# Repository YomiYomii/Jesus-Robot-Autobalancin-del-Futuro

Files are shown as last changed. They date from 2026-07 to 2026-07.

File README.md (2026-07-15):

# 🤖 Jesucristo, el Robot Auto-Balancín del Futuro
 
<p align="center">
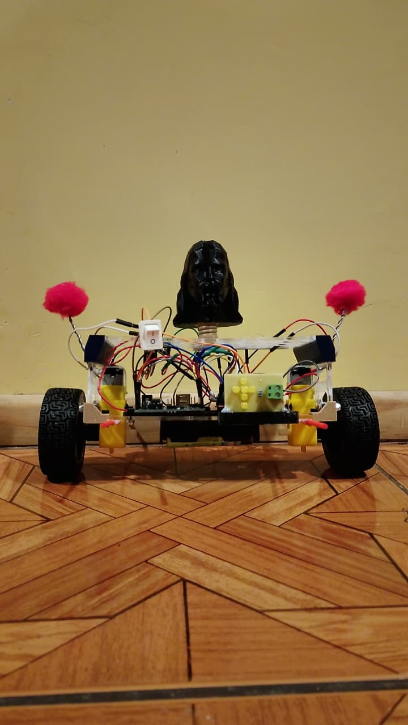
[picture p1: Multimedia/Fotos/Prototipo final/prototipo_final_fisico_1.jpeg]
  
</p>
<p align="center">
  <i>Robot auto-balancín de 2 ruedas con control PID, inspirado en "Jesucristo, el robot del futuro" de Zorman.</i>
</p>

<p align="center">
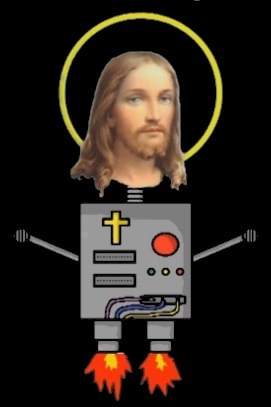
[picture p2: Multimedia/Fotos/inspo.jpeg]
Inspiración: Jesucristo, el robot del futuro
  <br>
  <i>Referencia de inspiración.</i>
</p>
 
- [Descripción](#-descripción)
- [Galería del proyecto](#-galería-del-proyecto)
- [Estructura del repositorio](#-estructura-del-repositorio)
- [Integrantes](#-integrantes)
- [Curso y agradecimientos](#-curso-y-agradecimientos)
- [Referencias](#-referencias)

## Descripción
 
Este proyecto consiste en el diseño, manufactura y programación de un **mini robot auto-balancín** de 2 ruedas, inspirado estéticamente en *Jesucristo, el robot del futuro*, personaje de la canción homónima de Zorman.
 
El robot utiliza un **sensor/giroscopio MPU6050** para medir su ángulo de inclinación y un **controlador PID** (implementado en Arduino IDE) para calcular la señal de corrección enviada a dos motores DC mediante un driver L298N, logrando mantener el equilibrio de forma autónoma.
 
El desarrollo pasó por múltiples iteraciones de diseño CAD y prototipado físico (impresión 3D FDM y corte láser en acrílico), hasta llegar a una versión final que integra mejoras estéticas (cruz de LEDs, brazos de alambre, cabeza) y estructurales (mejor manejo de cableado y sujeción de componentes).
 
Este repositorio reemplaza el informe final del proyecto, documentando de forma abierta y reproducible todo el proceso de diseño, fabricación, electrónica y control.

## Galería del proyecto

| Prototipo final | Diagrama de control | Constantes PID |
|:---:|:---:|:---:|
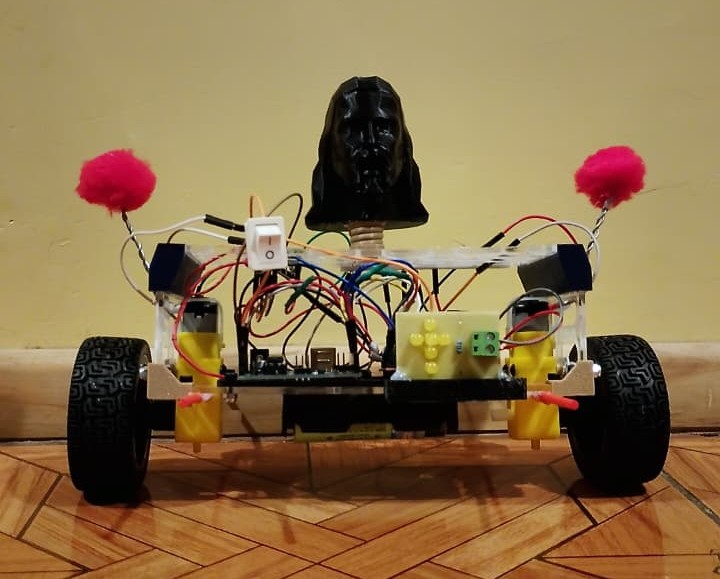
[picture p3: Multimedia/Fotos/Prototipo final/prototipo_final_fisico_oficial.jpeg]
Prototipo
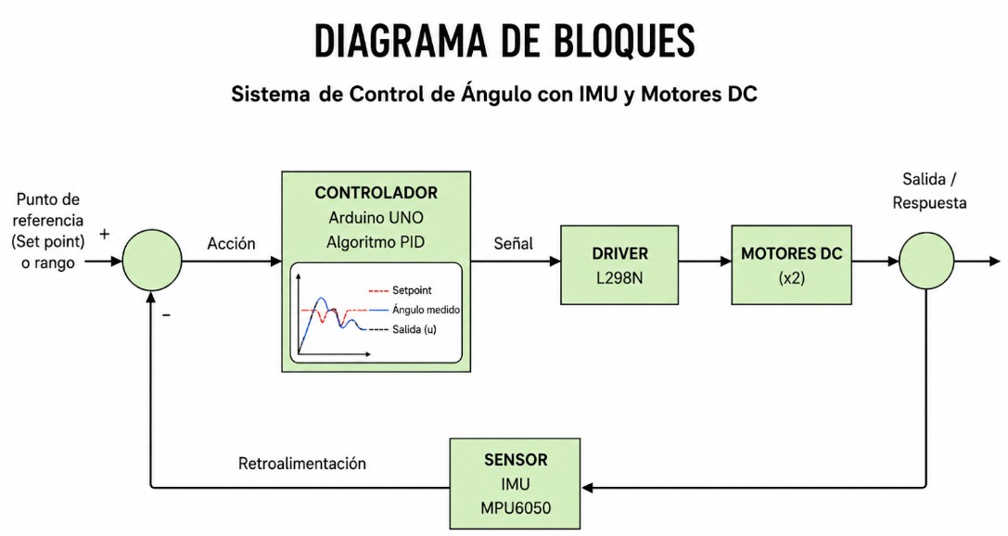
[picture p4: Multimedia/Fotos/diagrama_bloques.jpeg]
Diagrama de bloques
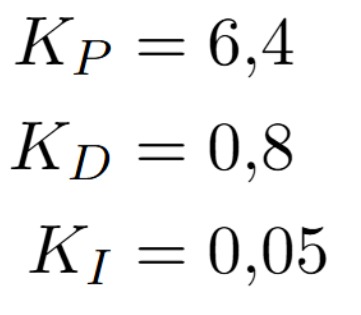
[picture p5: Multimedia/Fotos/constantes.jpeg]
PID
|  |  |  |

| Iteración 1 | Iteración 2 |
|:---:|:---:|
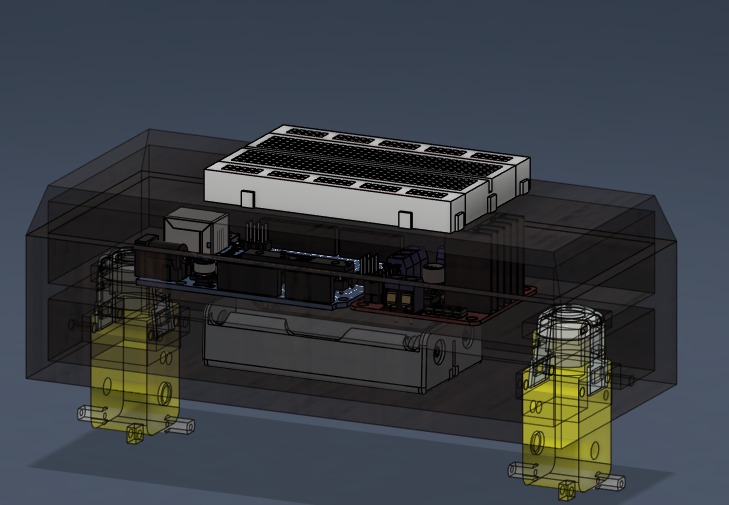
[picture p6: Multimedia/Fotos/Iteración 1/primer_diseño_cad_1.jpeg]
Iteración 1
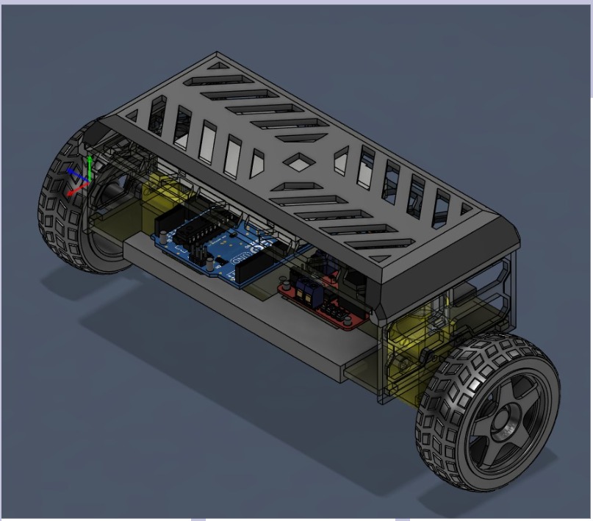
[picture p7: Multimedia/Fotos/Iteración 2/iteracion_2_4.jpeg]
Iteración 2
|  |  |

| Iteración 3 | Prototipo final |
|:---:|:---:|
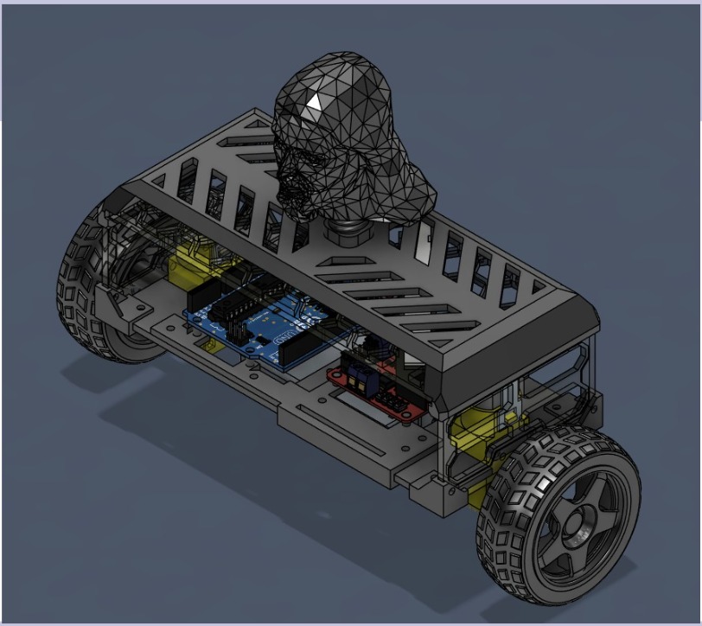
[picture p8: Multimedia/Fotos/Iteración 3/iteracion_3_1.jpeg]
Iteración 3
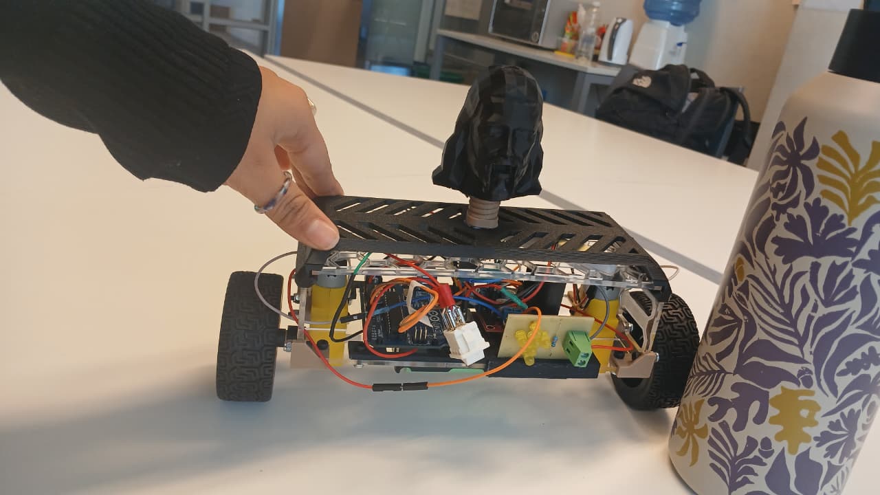
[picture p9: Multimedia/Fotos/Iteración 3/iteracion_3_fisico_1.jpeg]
Iteración 3
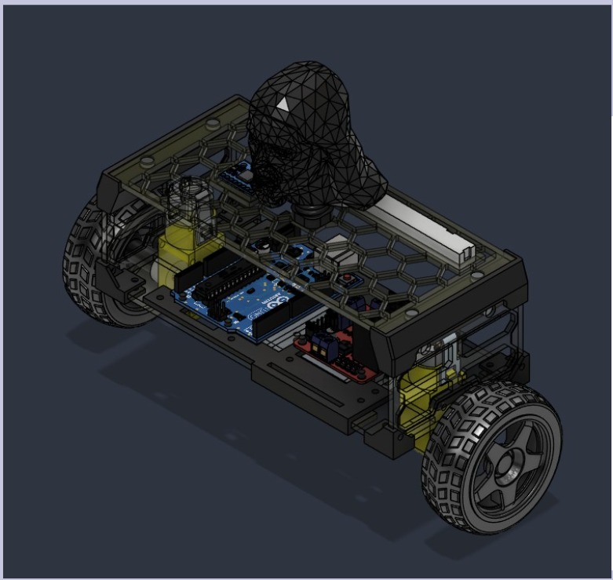
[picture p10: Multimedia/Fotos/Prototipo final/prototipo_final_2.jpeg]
Prototipo final
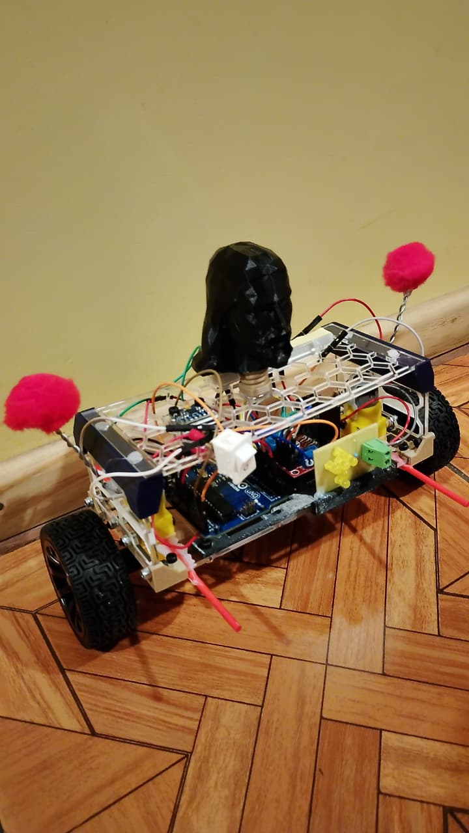
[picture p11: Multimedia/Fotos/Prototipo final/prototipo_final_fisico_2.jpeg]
Prototipo final
|   |  |

> 📌 Más imágenes y videos del proceso y resultados experimentales en [`Multimedia/`](/Multimedia/).
 
---
 
## Estructura del repositorio
 
```
├── README.md                     # Este archivo
├── CAD/                          # Modelos y planos de fabricación
│   ├── Fusion360/                # Archivos nativos .f3d / .f3z
│   ├── STEP/                     # Exportaciones .step
│   └── planos_corte_laser/       # Planos 2D para corte láser (.dxf/.pdf)
├── componentes_y_materiales/     # Lista de materiales (BOM)
│   └── BOM.md
├── codigo/                       # Firmware del robot
│   ├── src/                      # Código Arduino IDE comentado
│   └── diagrama_logica.png       # Diagrama de flujo del programa
├── diagramas_electronicos_y_control/
│   ├── esquematico_electrico.png
│   └── diagrama_control_PID.png
└── registros_audiovisuales/      # Fotos y videos de avances/resultados
```
 
---
 
## Integrantes
 
- Esteban Ortiz
- Millaray González
- Valentina Gómez
- Vicente Leiva
---
 
## Curso y agradecimientos
 
Proyecto desarrollado para el curso **ME4250-2 — Mecatrónica**, semestre 2026-1, Departamento de Ingeniería Mecánica, Facultad de Ciencias Físicas y Matemáticas, Universidad de Chile.
 
Agradecemos al **Laboratorio de Mecatrónica y Robótica (LEMUR)** por facilitar el espacio, herramientas de fabricación (impresión 3D y corte láser) y equipos utilizados durante el desarrollo del proyecto.

Agradecemos también al **FabLab** por el corte láser e impresión 3D de las piezas del robot.
 
---
 
## Referencias
 
- Zorman. *Jesucristo, el robot del futuro* (canción, 2013). Inspiración estética del proyecto.

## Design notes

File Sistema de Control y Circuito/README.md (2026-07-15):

# Diagramas electrónicos y de control
 
Esta carpeta contiene la documentación gráfica del sistema electrónico y de control del robot auto-balancín.
 
## Índice
 
- [Diagrama esquemático electrónico](#-diagrama-esquemático-electrónico)
- [Diagrama del sistema de control](#-diagrama-del-sistema-de-control)

## Diagrama esquemático electrónico
 
<p align="center">
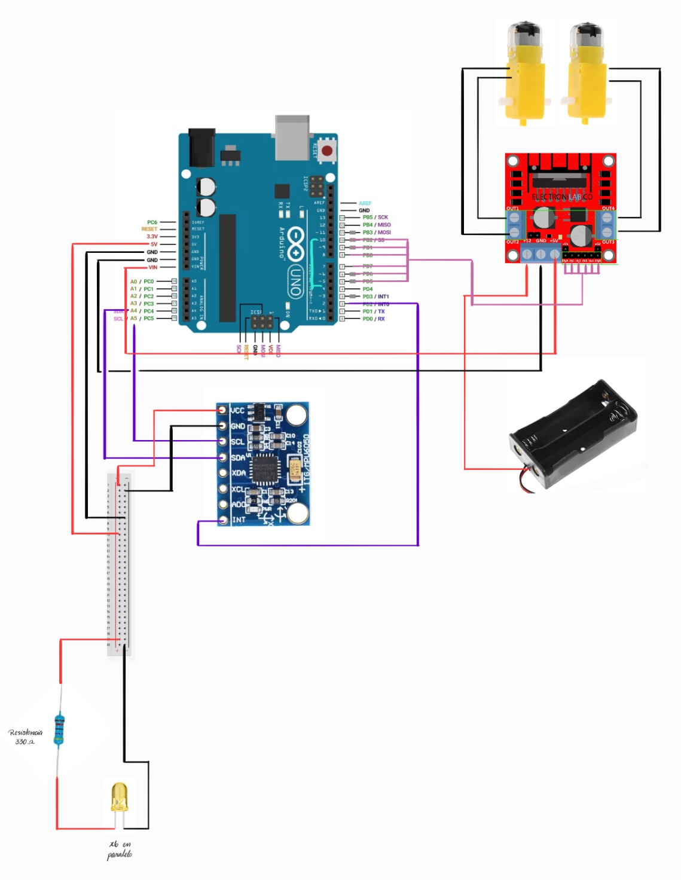
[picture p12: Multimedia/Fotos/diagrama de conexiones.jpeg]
Diagrama de conexiones del robot
  
</p>
 
Muestra las conexiones físicas entre todos los componentes electrónicos del robot:
 
- **Arduino** ↔ **MPU6050**: comunicación I2C (pines SDA/SCL), alimentación 3.3V/5V y GND
- **Arduino** ↔ **Driver L298N**: señales de control PWM (ENA/ENB) y dirección de giro (IN1-IN4)
- **Driver L298N** ↔ **Motores DC**: salidas de potencia hacia cada motor
- **Portapilas (2x12V)** ↔ **Driver L298N**: alimentación de potencia para los motores
- **Arduino** ↔ **LEDs amarillos**: salida digital/PWM para la cruz de luces
- Conexiones de **GND común** entre todas las etapas (Arduino, driver y alimentación de motores)

**Componentes representados:**
 
| Componente | Conexión principal |
|---|---|
| Arduino (Uno/Nano) | Controlador central |
| MPU6050 | I2C (SDA/SCL) |
| L298N | PWM + dirección (4 pines de control) |
| Motores DC (x2) | Salida de potencia del driver |
| Portapilas 2x12V | Alimentación de motores |
| LEDs amarillos | Salida digital Arduino |
 
---
 
## Diagrama del sistema de control
 
<p align="center">
  Diagrama de conexiones del robot
</p>
 
Representa el **diagrama de bloques en lazo cerrado** que describe cómo el robot mantiene el equilibrio:
 
```
Ángulo de     ┌───┐    Error   ┌─────────────┐   Señal PWM   ┌──────────┐   Voltaje   ┌─────────┐  Ángulo real
referencia ──►│ Σ │──────────► │  Controlador│──────────────►│  Driver  │────────────►│ Motores │────────────► (Robot)
   (0°)       └───┘            │     PID     │               │  L298N   │             │   DC    │
                 ▲             └─────────────┘               └──────────┘             └─────────┘       │
                 │                                                                                      │
                 │                      Retroalimentación (ángulo medido)                               │
                 └─────────────────────────── Sensor MPU6050 ◄──────────────────────────────────────────┘
```
 
**Descripción del lazo de control:**
 
1. **Punto de referencia**: ángulo objetivo (0°, robot vertical)
2. **Comparador (Σ)**: calcula el error entre el ángulo deseado y el ángulo medido
3. **Controlador PID**: procesa el error y calcula la acción correctiva, usando las constantes:
   - `Kp = 6.4`
   - `Kd = 0.8`
   - `Ki = 0.05`
4. **Driver L298N**: convierte la señal de control en voltaje/PWM aplicado a los motores
5. **Motores DC**: generan el movimiento correctivo de las ruedas
6. **Planta (robot)**: responde físicamente, cambiando su ángulo de inclinación
7. **Sensor MPU6050**: mide el nuevo ángulo y retroalimenta el sistema, cerrando el lazo
Las constantes PID se obtuvieron mediante el método de **Ziegler-Nichols** como punto de partida, y se ajustaron posteriormente mediante **prueba y error** hasta lograr un balance estable.

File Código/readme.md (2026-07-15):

## Diagrama lógica 

<p align="center">
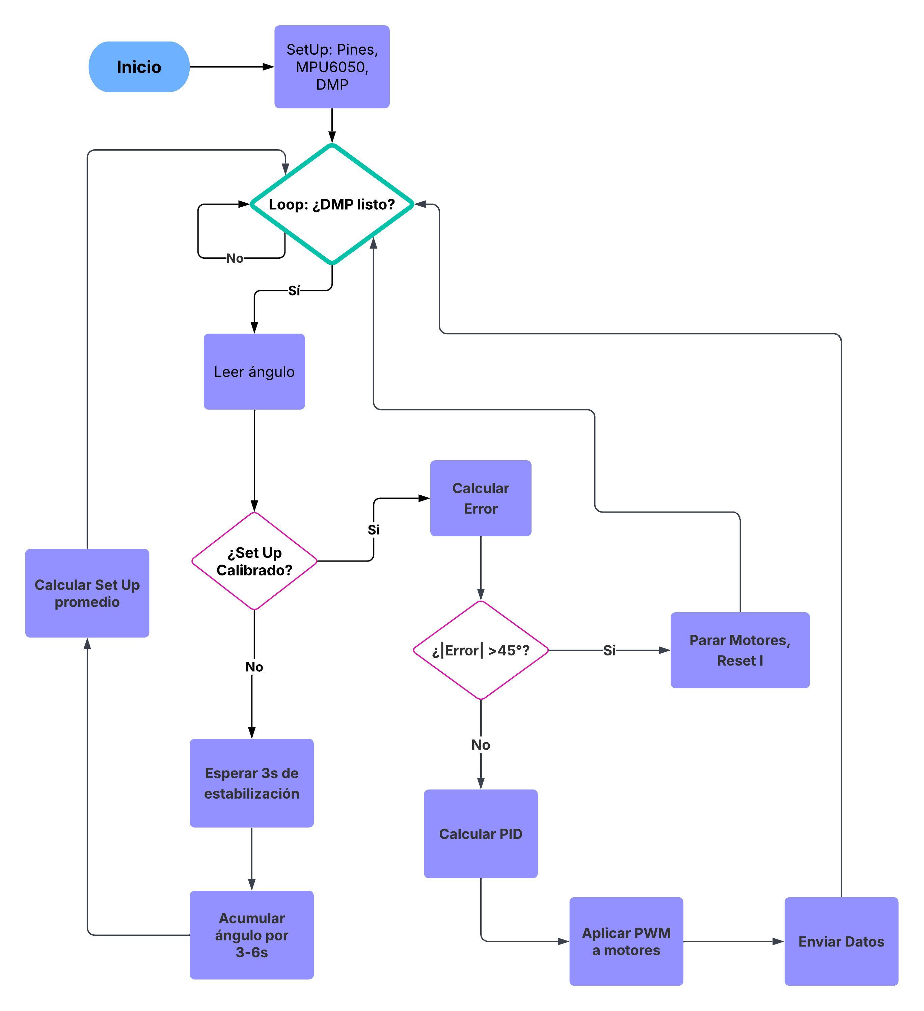
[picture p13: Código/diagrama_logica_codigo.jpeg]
Diagrama de conexiones del robot
  
</p>

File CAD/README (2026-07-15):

Referencias para Modelo 3D cabeza de jesus: https://cults3d.com/es/modelo-3d/arte/jesucristo-el-robot-del-futuro-zorman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

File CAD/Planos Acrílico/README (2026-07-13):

Planos DFX usados para cortar en acrílico

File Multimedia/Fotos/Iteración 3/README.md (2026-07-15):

Acpa estan los registros de la 3era iteración realizada

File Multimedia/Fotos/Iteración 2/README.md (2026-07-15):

Acá estan las imagenes de la segunda iteración

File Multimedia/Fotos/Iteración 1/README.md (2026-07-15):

Acá se encuentran los registro de la primera interación

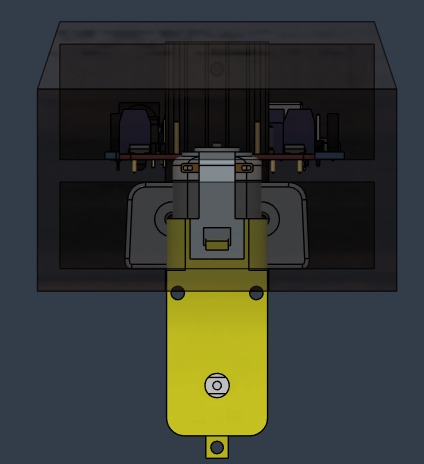
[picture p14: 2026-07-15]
Multimedia/Fotos/Iteración 1/primer_diseño_cad_2.jpeg

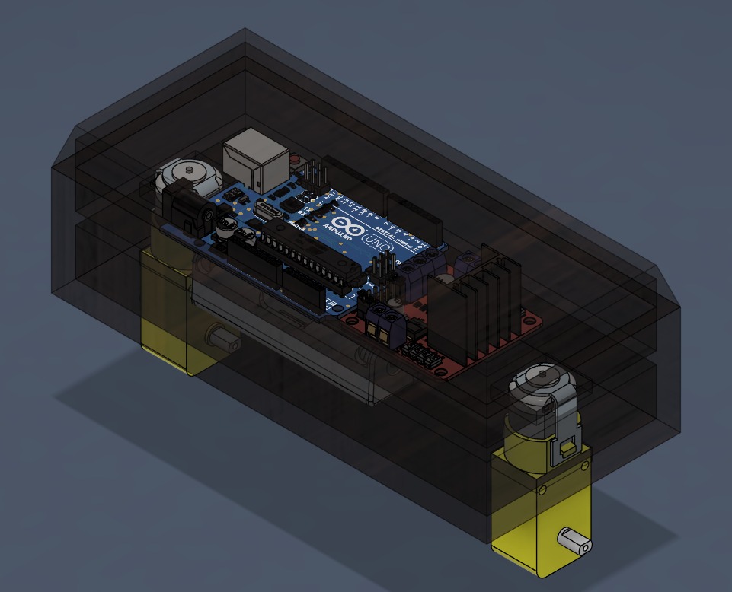
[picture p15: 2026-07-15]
Multimedia/Fotos/Iteración 1/primer_diseño_cad_4.jpeg

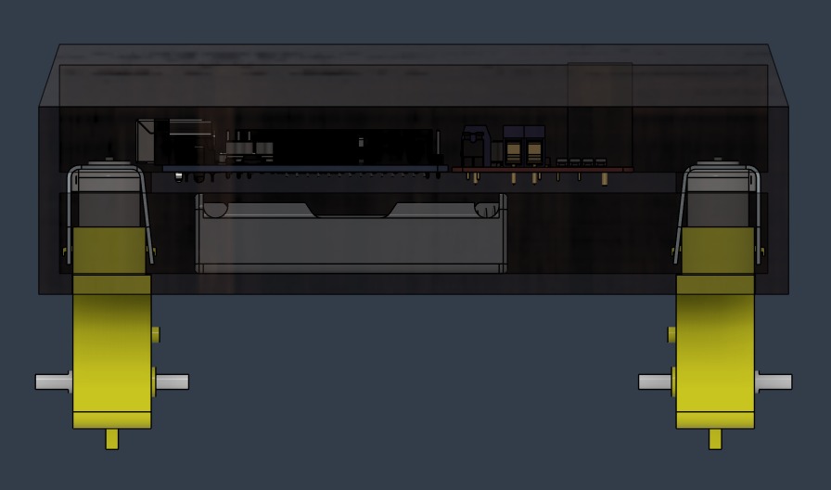
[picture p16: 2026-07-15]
Multimedia/Fotos/Iteración 1/primer_diseño_cad_3.jpeg

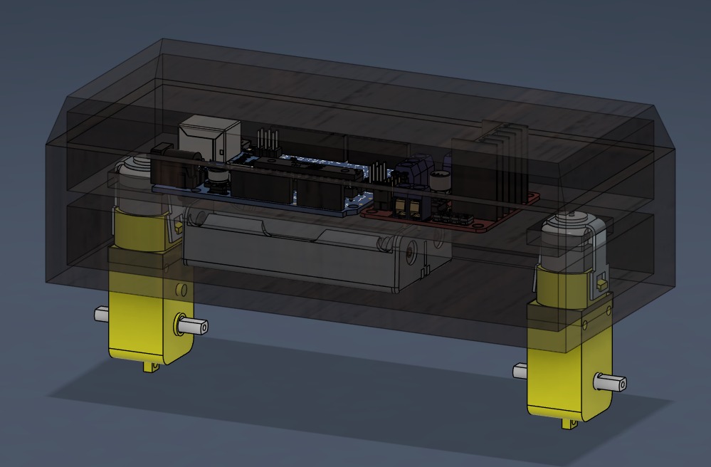
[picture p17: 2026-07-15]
Multimedia/Fotos/Iteración 1/primer_diseño_cad_5.jpeg

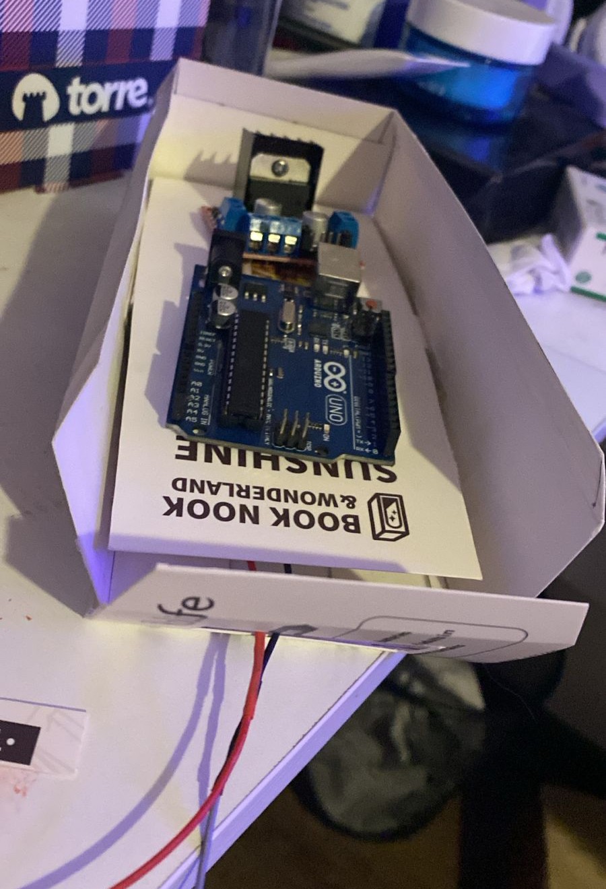
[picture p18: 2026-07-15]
Multimedia/Fotos/Iteración 1/primer_protoitpo_carton_3.jpeg

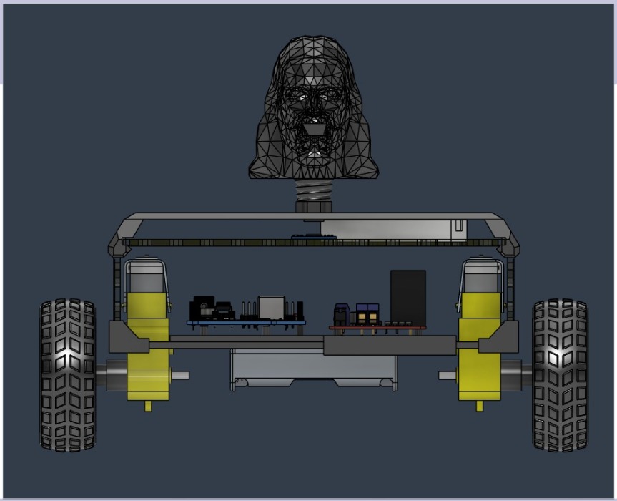
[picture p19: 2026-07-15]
Multimedia/Fotos/Iteración 3/iteracion_3_2.jpeg

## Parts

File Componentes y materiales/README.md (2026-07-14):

# Lista de Materiales (BOM)
 
Lista de componentes electrónicos y materiales utilizados en la fabricación del robot auto-balancín.

## Componentes electrónicos
 
| Componente | Cantidad | Función |
|---|---|---|
| Motor DC 6V | 2 | Tracción de las ruedas del robot |
| Sensor/giroscopio MPU6050 | 1 | Medición del ángulo de inclinación (IMU) |
| Driver de motores L298N | 1 | Control de potencia y sentido de giro de los motores |
| Arduino (Uno/Nano)* | 1 | Controlador principal, ejecuta el algoritmo PID |
| LED amarillo | 6 | Iluminación decorativa (cruz estética) |
| Portapilas para 2 baterías 12V | 1 | Alimentación eléctrica del sistema |
| Rueda 60 mm | 2 | Ruedas motrices |
| Breadboard parcial | 1 | Conexión y montaje de componentes electrónicos |
 
\* *Ajusta el modelo exacto de Arduino usado (Uno, Nano, Mini, etc.)*
 
## Materiales estructurales
 
| Material | Uso |
|---|---|
| PLA | Piezas impresas en 3D (FDM) |
| Acrílico 3 mm | Piezas cortadas con láser (chasis/estructura) |
| Imanes 6x2 mm | *(especificar uso: sujeción de piezas, tapas, etc.)* |
| Alambre | Brazos decorativos estilo Zorman |
| Pompones | Detalles decorativos |
| Pernos M3 x 30 mm | Sujeción estructural |
| Pernos M3 x 8 mm | Sujeción estructural |
 
---

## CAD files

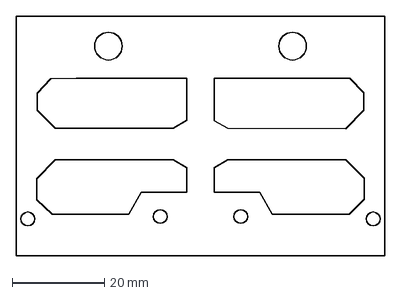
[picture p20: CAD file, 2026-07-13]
CAD/Planos Acrílico/Pared Corte Final.dxf
80.0 x 52.0 mm

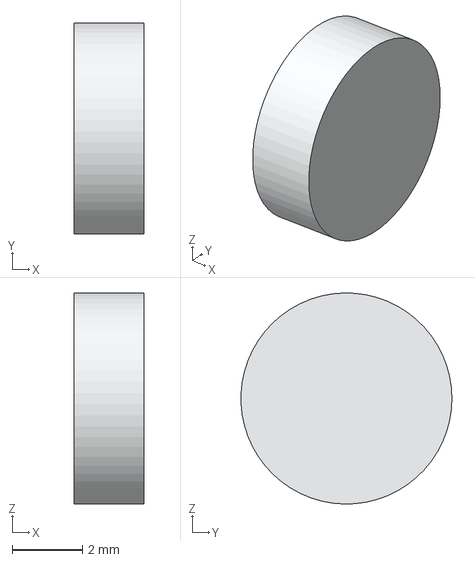
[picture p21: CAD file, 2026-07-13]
CAD/STEP/Componentes/Iman.step
2.00 x 6.00 x 6.00 mm

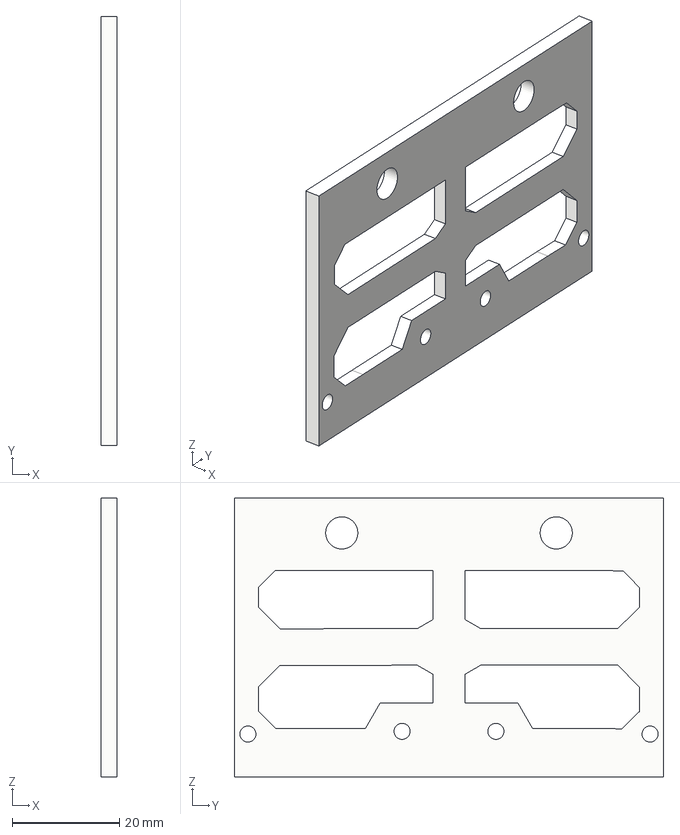
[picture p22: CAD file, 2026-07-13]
CAD/STEP/Piezas Base/Pared Derecha v2.step
3.00 x 80.0 x 52.0 mm

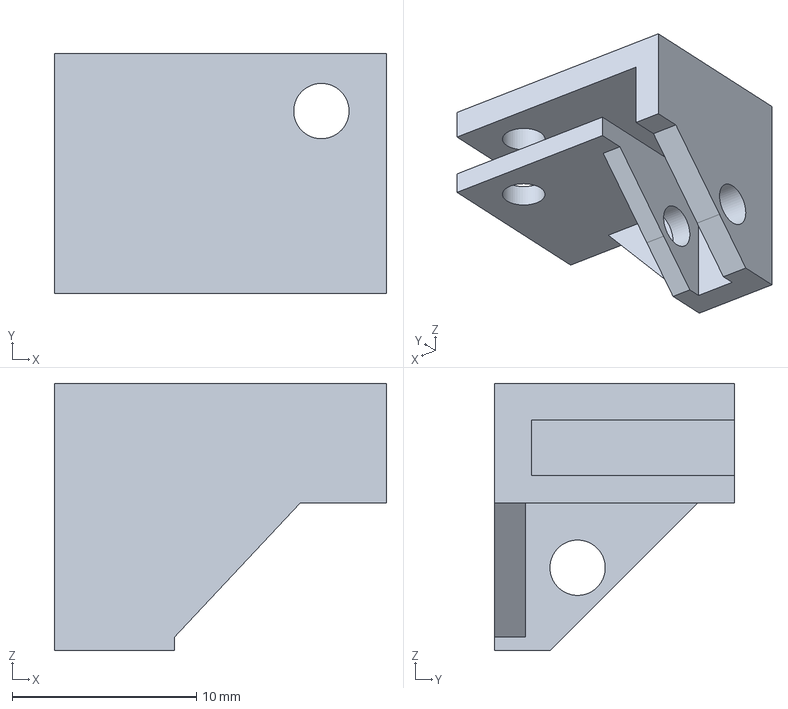
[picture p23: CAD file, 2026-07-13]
CAD/STEP/Soportes y Decoraciones/Soporte B D.step
18.0 x 13.0 x 14.5 mm

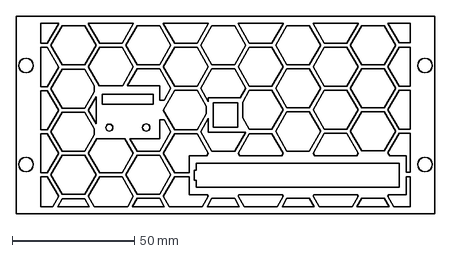
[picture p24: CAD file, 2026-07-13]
CAD/Planos Acrílico/Corte Panal.dxf
171.6 x 81.0 mm

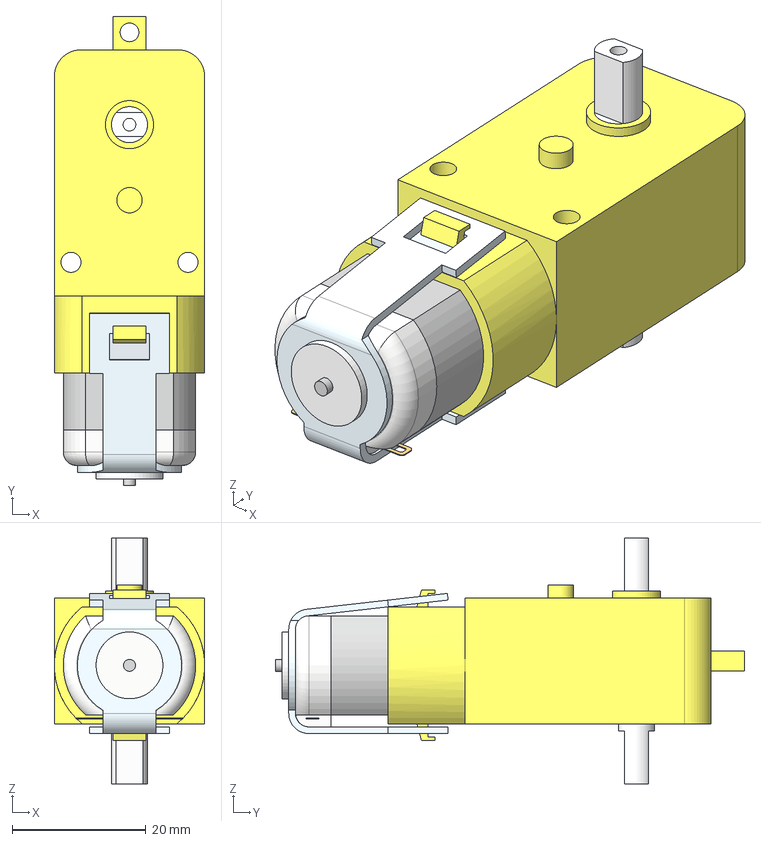
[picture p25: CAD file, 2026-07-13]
CAD/STEP/Componentes/Motor_DC_6V_con_Gearbox v2.step
22.5 x 70.2 x 36.8 mm
Surface 1

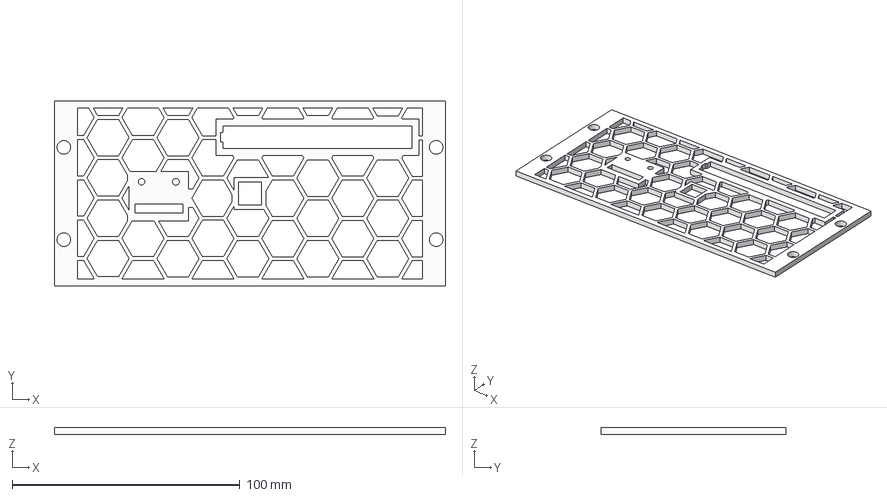
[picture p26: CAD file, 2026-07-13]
CAD/STEP/Piezas Base/Base Panal.step
171.6 x 81.0 x 3.00 mm

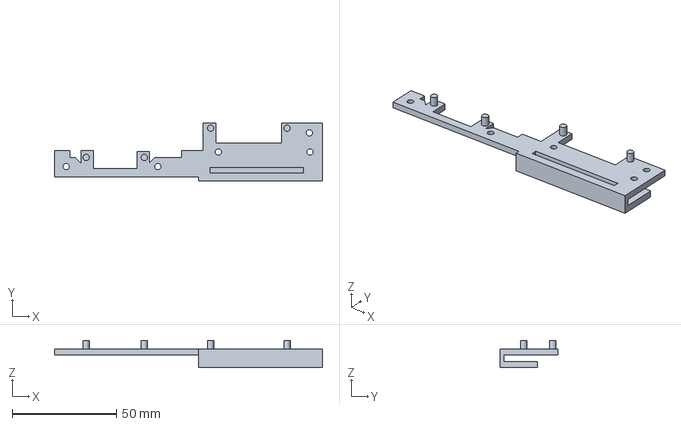
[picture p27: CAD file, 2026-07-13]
CAD/STEP/Soportes y Decoraciones/Soporte Frontal.step
128.6 x 28.0 x 13.0 mm

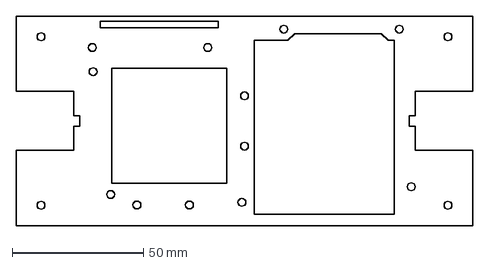
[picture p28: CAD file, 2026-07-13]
CAD/Planos Acrílico/Corte Base.dxf
174.0 x 80.0 mm

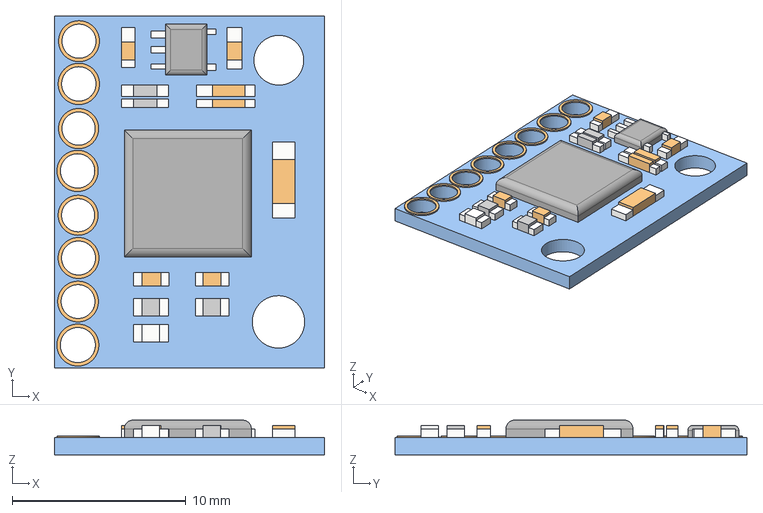
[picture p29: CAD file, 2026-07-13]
CAD/STEP/Componentes/MPU6050 v1.step
15.6 x 20.3 x 2.00 mm

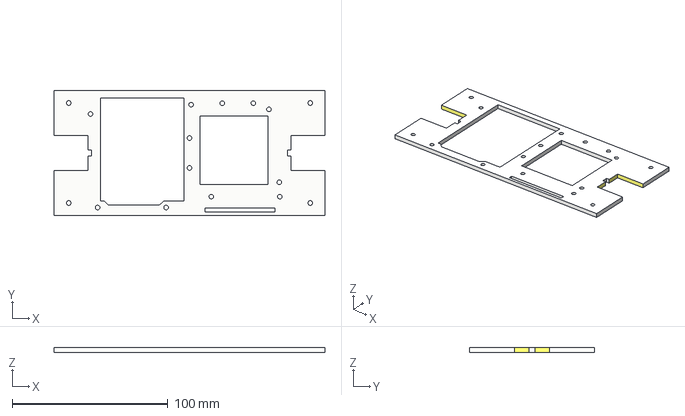
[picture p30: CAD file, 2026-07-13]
CAD/STEP/Piezas Base/Base.step
174.0 x 80.0 x 3.00 mm

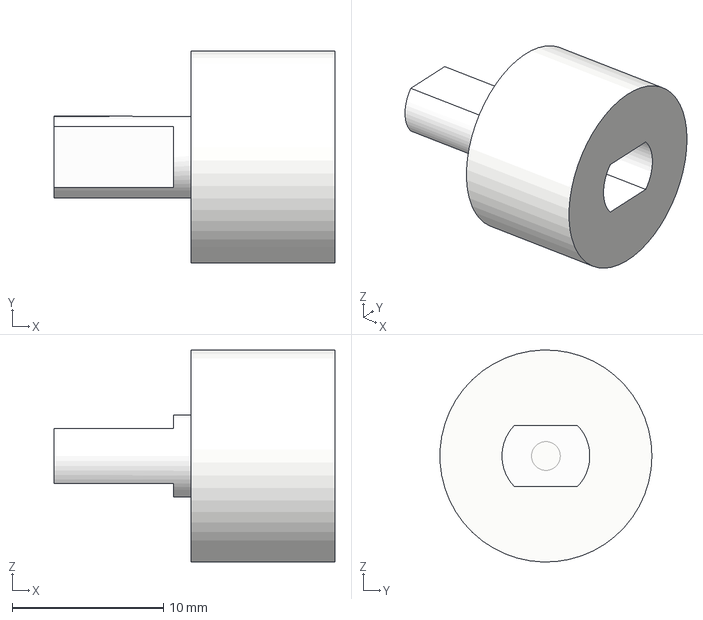
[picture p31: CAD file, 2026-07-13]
CAD/STEP/Soportes y Decoraciones/Soporte Ruedas v3.step
18.6 x 14.0 x 14.0 mm

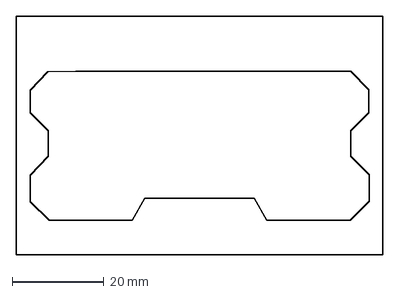
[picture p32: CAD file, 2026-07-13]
CAD/Planos Acrílico/Pared Grabado.dxf
80.0 x 52.0 mm

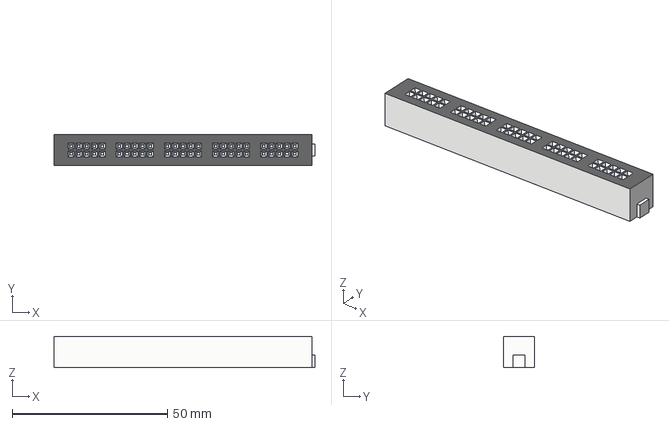
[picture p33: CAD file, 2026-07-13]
CAD/STEP/Componentes/Breadboard.step
84.0 x 10.0 x 10.0 mm

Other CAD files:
CAD/STEP/Piezas Base/Pared Izquierda.step
CAD/STEP/Soportes y Decoraciones/Soporte Trasero.step
CAD/STEP/Componentes/BatteryCase18650x2 v1.step
CAD/STEP/Soportes y Decoraciones/Soporte Cabeza.step
CAD/Fusion 360/Componentes/BatteryCase18650x2 v1.f3d
CAD/Fusion 360/Componentes/Breadboard.f3d
CAD/Fusion 360/Componentes/Iman.f3d
CAD/Fusion 360/Componentes/L298N_Driver v1.f3d
CAD/Fusion 360/Componentes/MPU6050 v1.f3d
CAD/Fusion 360/Componentes/Motor_DC_6V_con_Gearbox v2.f3d
CAD/Fusion 360/Piezas Base/Base Panal.f3d
CAD/Fusion 360/Piezas Base/Base.f3d
CAD/Fusion 360/Piezas Base/Pared Derecha v2.f3d
CAD/Fusion 360/Piezas Base/Pared Izquierda.f3d
CAD/Fusion 360/Soportes y Decoraciones/Jesucristo el robot del futuro cabeza v1.f3d
CAD/Fusion 360/Soportes y Decoraciones/Soporte A D.f3d
CAD/Fusion 360/Soportes y Decoraciones/Soporte A I.f3d
CAD/Fusion 360/Soportes y Decoraciones/Soporte B D.f3d
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

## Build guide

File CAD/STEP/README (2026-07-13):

DISCLAIMER: El ensamble en STEP se subio sin el arduino, driver, batterycase o breadboard debido a que era muy grande para subir a github

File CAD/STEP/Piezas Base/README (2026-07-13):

Aquí se incluyen las piezas base estructurales del CAD, principalmente hechas en acrílico

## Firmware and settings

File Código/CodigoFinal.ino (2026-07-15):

// ================================================================
// ===        Jesus Robot Autobalancín del Futuro               ===
// ================================================================

// Código INO del proyecto de mecatrónica jesus el robot autobalancin 
// del futuro.

//  Integrantes:
// Vicente Leiva
// Millaray González
// Valentina Gómez
// Esteban Ortiz


// ================================================================
// ===                    Librerias Usadas                      ===
// ================================================================


#include "I2Cdev.h"
#include "MPU6050_6Axis_MotionApps20.h"
#include <Wire.h> // Inclusión forzada para evitar errores de tipo

MPU6050 mpu;

// ================================================================
// ===         DEFINIMOS VARIABLES GLOBALES Y PINES             ===
// ================================================================

// Pines L298N
const int PinL1 = 7;    
const int PinL2 = 8;    
const int PinR1 = 5;    
const int PinR2 = 6;    
const int PwmL  = 10;   
const int PwmR  = 9;    

// CONSTANTES PID AJUSTADAS 
float Kp = 80.0;
float Kd = 1;  
float Ki = 0.05; 

float setpoint = 0.0;   // Se calculará automáticamente en el setup dinámico
float angulo_actual = 0;    //Valor asociado al ángulo que detecta en el momento el sensor 
float error = 0, error_anterior = 0;
float P = 0, I = 0, D = 0;  //Valores asociados a PID
float derivada_filtrada = 0; // Filtro para robustez ante perturbaciones
float u = 0;     //Velocidad motor        

unsigned long tiempo_anterior = 0; //Usado para definir la diferencia entre angulo y tiempo

// Variables del MPU6050
bool dmpReady = false;
uint8_t mpuIntStatus;
uint16_t packetSize;
uint16_t fifoCount;
uint8_t fifoBuffer[64];
Quaternion q;
VectorFloat gravity;
float ypr[3];

volatile bool mpuInterrupt = false;
void dmpDataReady() { mpuInterrupt = true; }

// Variables para Auto-Setpoint (Calibración Dinámica del Centro de Masa)
bool setpoint_configurado = false;
float suma_angulos = 0;
int contador_lecturas = 0;

// ================================================================
// ===                         SETUP DEL ROBOT                  ===
// ================================================================

void setup() {
    pinMode(PinR1, OUTPUT); pinMode(PinR2, OUTPUT); pinMode(PwmR, OUTPUT);
    pinMode(PinL1, OUTPUT); pinMode(PinL2, OUTPUT); pinMode(PwmL, OUTPUT);

    // Inicialización I2C Segura con Salvavidas Anti-Congelamiento
    Wire.begin();
    Wire.setClock(400000); 
    Wire.setWireTimeout(3000, true); // Mitigación de I2C Lockup por ruido electromagnético

    Serial.begin(115200); 
    while (!Serial);

    mpu.initialize();
    uint8_t devStatus = mpu.dmpInitialize();

    // OFFSETS DE CALIBRACIÓN ESTÁTICA (Valores fijos de la estructura, definidos usando IMUZero)
    mpu.setXAccelOffset(605);
    mpu.setYAccelOffset(-4743);
    mpu.setZAccelOffset(1481);
    mpu.setXGyroOffset(-11);
    mpu.setYGyroOffset(30);
    mpu.setZGyroOffset(17);

    if (devStatus == 0) {
        mpu.setDMPEnabled(true);
        attachInterrupt(digitalPinToInterrupt(2), dmpDataReady, RISING);
        mpuIntStatus = mpu.getIntStatus();
        dmpReady = true;
        packetSize = mpu.dmpGetFIFOPacketSize();
    } else {
        Serial.println(F("Error inicializando DMP"));
    }
}

// ================================================================
// ===                      LOOP PRINCIPAL                      ===
// ================================================================

void loop() {
    if (!dmpReady) return;

    if (mpu.dmpGetCurrentFIFOPacket(fifoBuffer)) {
        leerSensores();
        
        // --- RUTINA DE AUTO-SETPOINT (Calibración Adaptativa al Centro de Masa) ---
        if (!setpoint_configurado) {
            unsigned long tiempo_actual = millis();
            
            if (tiempo_actual < 3000) {
                // Seg 0 a 3: Estabilización del filtro inercial del MPU
                Serial.println("Estabilizando filtro inercial...");
            } 
            else if (tiempo_actual >= 3000 && tiempo_actual < 6000) {
                // Seg 3 a 6: Muestreo y acumulación para cálculo del punto de equilibrio real
                suma_angulos += angulo_actual;
                contador_lecturas++;
                Serial.println("CALIBRANDO... ¡MANTEN EL ROBOT EN EQUILIBRIO FÍSICO!");
            } 
            else {
                // Cálculo del valor esperado del Setpoint mecánico
                setpoint = suma_angulos / contador_lecturas;
                setpoint_configurado = true;
                tiempo_anterior = millis(); // Inicialización limpia del delta de tiempo para el PID
                Serial.print("=== SETPOINT DINÁMICO FIJADO EN: ");
                Serial.print(setpoint);
                Serial.println(" GRADOS ===");
            }
            return; // Bloqueo de seguridad: No energizar motores durante la calibración
        }
        // --------------------------------------------------------------------------

        // Manejo de Seguridad Estructural (Corte por Ángulo de Caída)
        if (abs(error) < 45.0) { 
            calcularPID();
            controlarMotores(u);
        } else {
            controlarMotores(0); // Parada de emergencia de los actuadores
            I = 0; 
            u = 0;
        }

        imprimirDatosPlotter();
    }
}

// ================================================================
// ===                   MÓDULO 1: SENSORES                     ===
// ================================================================

void leerSensores() {
    mpu.dmpGetQuaternion(&q, fifoBuffer);
    mpu.dmpGetGravity(&gravity, &q);
    mpu.dmpGetYawPitchRoll(ypr, &q, &gravity);
    
    // Extracción limpia del Pitch en grados usando el DMP interno
    angulo_actual = ypr[1] * 180.0 / PI; 
}

// ================================================================
// ===                     MÓDULO 2: PID                        ===
// ================================================================

void calcularPID() {
    unsigned long tiempo_actual = millis();
    float dt = (tiempo_actual - tiempo_anterior) / 1000.0;
    if (dt <= 0.0) dt = 0.01; 
    tiempo_anterior = tiempo_actual;

    // Cálculo del error dinámico respecto al setpoint autocalibrado
    error = setpoint - angulo_actual;

    // Acción Proporcional
    P = Kp * error;

    // Acción Integral con Mitigación de Saturación (Anti-Windup)
    I += Ki * error * dt;
    if (error * error_anterior < 0) { I = 0; } // Reseteo al cruzar por el cero
    if (I > 200) I = 200;                      // Saturación de seguridad
    if (I < -200) I = -200;

    // Acción Derivativa con Filtro Pasa-Bajas para Atenuación de Ruido (Robustez)
    float derivada_cruda = (error - error_anterior) / dt;
    derivada_filtrada = (0.7 * derivada_cruda) + (0.3 * derivada_filtrada); // Suaviza picos por perturbación
    D = Kd * derivada_filtrada;

    // Señal de control u(t)
    u = P + I + D;
    error_anterior = error;
}

// ================================================================
// ===                   MÓDULO 3: MOTORES                      ===
// ================================================================

void controlarMotores(float senal_control) {
    int pwm_salida = abs(senal_control);
    
    if (pwm_salida > 255) pwm_salida = 255;
    
    // Compensación de la zona muerta por fricción estática
    if (pwm_salida > 0 && pwm_salida < 15) pwm_salida = 15; 

    if (senal_control > 0) {
        digitalWrite(PinL1, HIGH); digitalWrite(PinL2, LOW);
        digitalWrite(PinR1, HIGH); digitalWrite(PinR2, LOW);
        analogWrite(PwmL, pwm_salida);
        analogWrite(PwmR, pwm_salida);
    } 
    else if (senal_control < 0) {
        digitalWrite(PinL1, LOW); digitalWrite(PinL2, HIGH);
        digitalWrite(PinR1, LOW); digitalWrite(PinR2, HIGH);
        analogWrite(PwmL, pwm_salida);
        analogWrite(PwmR, pwm_salida);
    } 
    else {
        analogWrite(PwmL, 0);
        analogWrite(PwmR, 0);
    }
}

// ================================================================
// ===                   SERIAL PLOTTER                         ===
// ================================================================

void imprimirDatosPlotter() {
    // Entrega las métricas cuantitativas exactas exigidas por la rúbrica final
    Serial.print("Setpoint:"); Serial.print(setpoint); Serial.print(",");
    Serial.print("Angulo:"); Serial.print(angulo_actual); Serial.print(",");
    Serial.print("Error:"); Serial.print(error); Serial.print(","); 
    Serial.print("PWM_u:"); Serial.println(u);
}

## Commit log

2026-07-13 Add README for 3D printed small parts
2026-07-13 Create README for CAD structural base parts
    Added a README file for structural base parts in CAD.
2026-07-14 Create Componentes y materiales (Lista de Materiales, Bill of Materials BOM)
2026-07-14 Update and rename Componentes y materiales (Lista de Materiales, Bill of Materials BOM) to Componentes y materiales/lista.md
